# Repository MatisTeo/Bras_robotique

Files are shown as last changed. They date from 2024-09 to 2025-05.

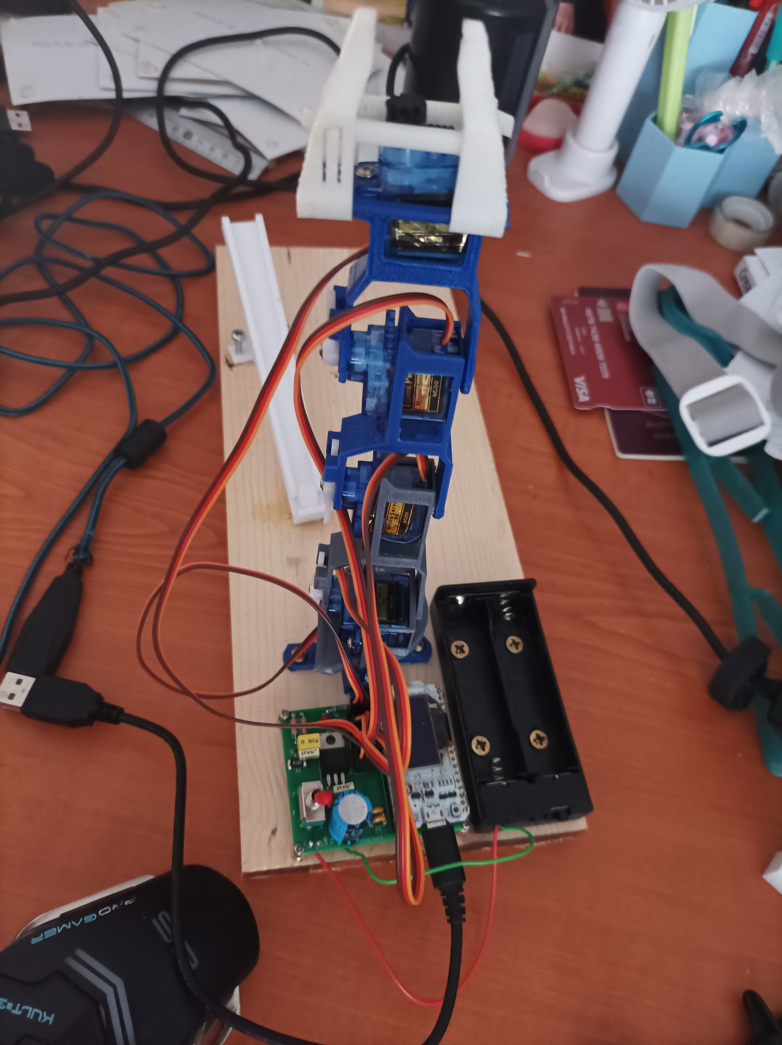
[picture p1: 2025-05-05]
Divers/photos/bras_robotique_assemblé_angle2.jpg

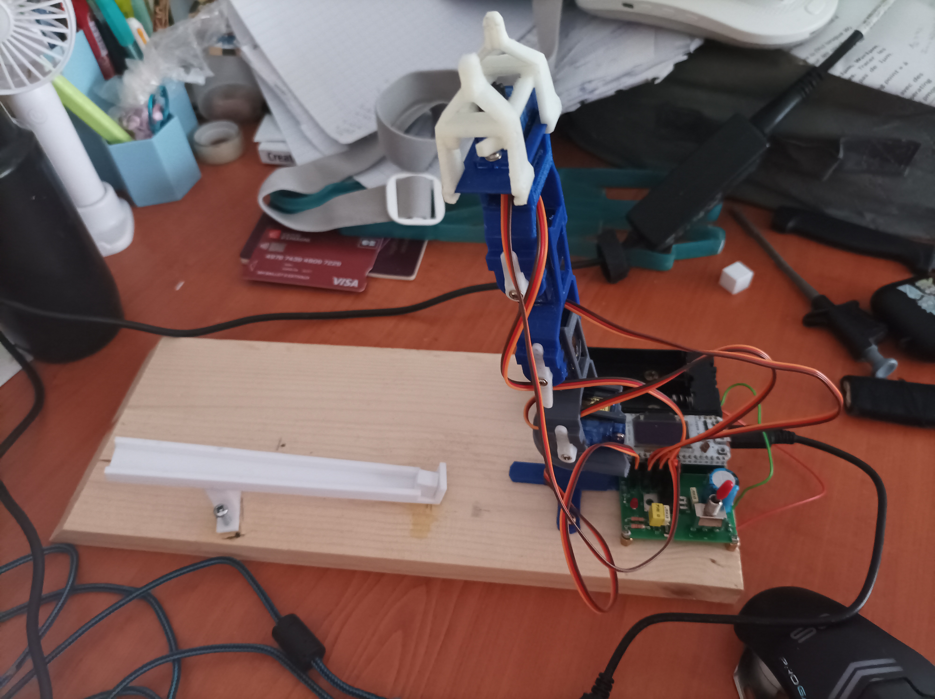
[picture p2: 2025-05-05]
Divers/photos/bras_robotique_assemblé_angle3.jpg

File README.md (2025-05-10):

# 🤖 Projet Bras Robotique Contrôlé par Gant Connecté

## 🎥 Démonstration vidéo
Regarder la vidéo sur YouTube (https://www.youtube.com/watch?v=8cOm21cPcBU)

## 📘 Présentation

Ce projet consiste à développer un **bras robotique à faible coût**, capable d'exécuter :
- des **mouvements automatiques prédéfinis**
- un **contrôle manuel à distance** à l'aide d’un **gant connecté**

L'objectif est de démontrer une alternative simple et économique pour la télémanipulation dans des environnements industriels.

## 🧠 Membres du projet
- **Téo Baillot d’Estivaux** — responsable software, modélisation 3D, banc de test
- **Matis Jaquet** — responsable hardware, PCB, assemblage électronique

## 🔧 Fonctionnalités
- Contrôle **automatique** via séquences programmées
- Contrôle **manuel en temps réel** via un gant avec capteur flex + MPU-6050
- Communication **sans fil via ESP-NOW (Wi-Fi)** entre gant et bras
- Structure imprimée en 3D, légère et modulaire
- Retour d’effort par détection de courant via INA219

## 📂 Contenu du dépôt
- `Hardware/` : Schémas et PCB sous KiCad
- `Software/` : Codes Arduino pour l’émetteur (gant) et le récepteur (bras)
- `Photos/Spécification/` : Images du montage
- `Memoire_Baillot_Jaquet.pdf` : Mémoire complet du projet (ELEC4 FISA 2024/2025)

## 🛠️ Composants utilisés
- 2x ESP32
- 1x MPU-6050 (accéléromètre)
- 1x capteur flex
- 5x servomoteurs SG90
- 1x INA219
- 1x bouton poussoir
- Câblage, breadboards, batteries

## 🚀 Instructions de montage
1. Imprimer les pièces 3D du bras
2. Souder les composants sur les PCB fournis
3. Assembler le gant en cousant les composants selon le schéma
4. Flasher les codes sur les ESP32 avec Arduino IDE
5. Alimenter les deux systèmes et tester les modes automatique et manuel

## 📎 Liens utiles
- [🔗 Dépôt GitHub](https://github.com/MatisTeo/Bras_robotique)
- [📄 Mémoire complet (PDF)](./Divers/Memoire_Baillot_Jaquet.pdf)

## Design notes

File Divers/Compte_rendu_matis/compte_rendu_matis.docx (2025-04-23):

Compte rendu des séances

Séance du 11 septembre :

Cette séance était destinée à choisir le projet. Nous avons donc décidé de faire une pince robotisée capable de récupérer le plus d'objets différents. Cette pince va être contrôlée grâce à un accéléromètre et un capteur de flexion. Le but est de faire bouger la main de droite à gauche pour faire bouger le bras articulé et de fermer le doigt pour fermer la pince grâce au capteur flex. Toutes les informations vont être transmises grâce à une connexion Bluetooth.

Séance du 23 septembre :

Durant cette séance, j'ai travaillé sur la création du git et la connexion du répertoire local de l'ordinateur au répertoire en ligne sur GitHub en utilisant une connexion SSH. De plus, pour développer le code nécessaire au fonctionnement des servomoteurs, j'ai dû installer l'environnement Arduino et les drivers pour piloter les ports de communication. Cette étape a pris plus de temps que prévu en raison de problèmes avec les drivers CH341 et CP210. Une fois ces problèmes résolus, tout était fonctionnel. Nous avons alors pu tester les servomoteurs pour comprendre leur fonctionnement.

Séance du 25 Novembre :

Au début de cette séance, les valeurs renvoyées par l'accéléromètre fluctuaient beaucoup trop pour pouvoir être traitées dans le code, ce qui provoquait des mouvements inopinés de la pince. Pour comprendre plus précisément la plage de tensions renvoyées par l'accéléromètre, j'ai décidé d'utiliser un oscilloscope pour observer la plage ainsi que les variations de tension.

Capture d'écran de l'oscilloscope en sortie de l'accéléromètre.

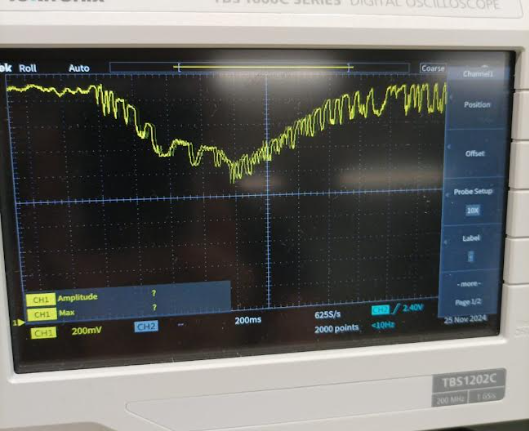
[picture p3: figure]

Interprétation :

Interprétation : Selon la capture d'écran de l'oscilloscope en sortie de l'accéléromètre, nous pouvons observer que les variations de tension de l'accéléromètre sont d'approximativement 600 millivolts pour un mouvement de 180° avec l'accéléromètre. Le problème que l'on peut constater, ce sont les perturbations - le bruit qui est de l'ordre de 250 à 200 millivolts. C'est donc ce bruit qui crée des perturbations lorsque l'on veut capturer la donnée de l'accéléromètre. Pour remédier à cela, nous avons eu l'idée de mettre un condensateur entre la sortie et le GND afin de lisser cette tension. Après d'autres mesures, malheureusement, cela n'a pas été utile et les perturbations restaient les mêmes. La deuxième solution a été la mise en place d'un filtre RC qui a pour valeur tau = 1/RC = 5ms, car nous capturons la valeur qui est renvoyée par l'accéléromètre tous les 50ms = 10 tau. Une fois le filtre en place, nous avons observé que les valeurs renvoyées étaient moins fluctuantes, les perturbations ont été divisées par 2, mais cela ne reste pas admissible. Une fois le filtre en place, nous avons observé que les valeurs renvoyées étaient moins fluctuantes, les perturbations ont été divisées par 2, mais cela ne reste pas admissible.

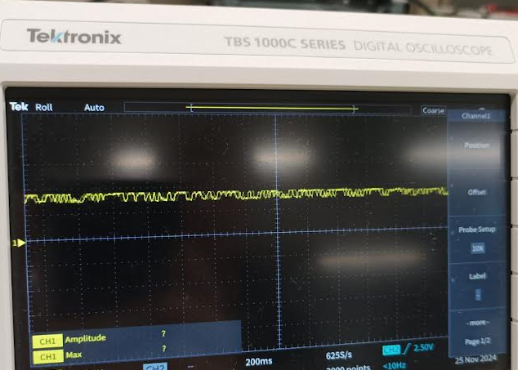
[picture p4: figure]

Séance du 26 Novembre :

J'ai débuté cette séance en consultant la documentation de l'accéléromètre pour essayer de comprendre l'origine de ces perturbations et notamment les variations de tension annoncées par le constructeur. Après cela, nous nous sommes aperçus que le problème venait plutôt du code, et après un réglage permettant de faire du filtrage numérique, il s'est avéré que les valeurs étaient enfin justes. Ensuite, je me suis penché sur la problématique de la connexion par Bluetooth et nous avons découvert que les cartes TTGO étaient déjà équipées de modules Bluetooth. Durant cette séance, j'en ai aussi profité pour commencer la conception du schéma électrique pour la carte qui sera mise sur le gant côté utilisateur.

Début du schéma préliminaire de la carte

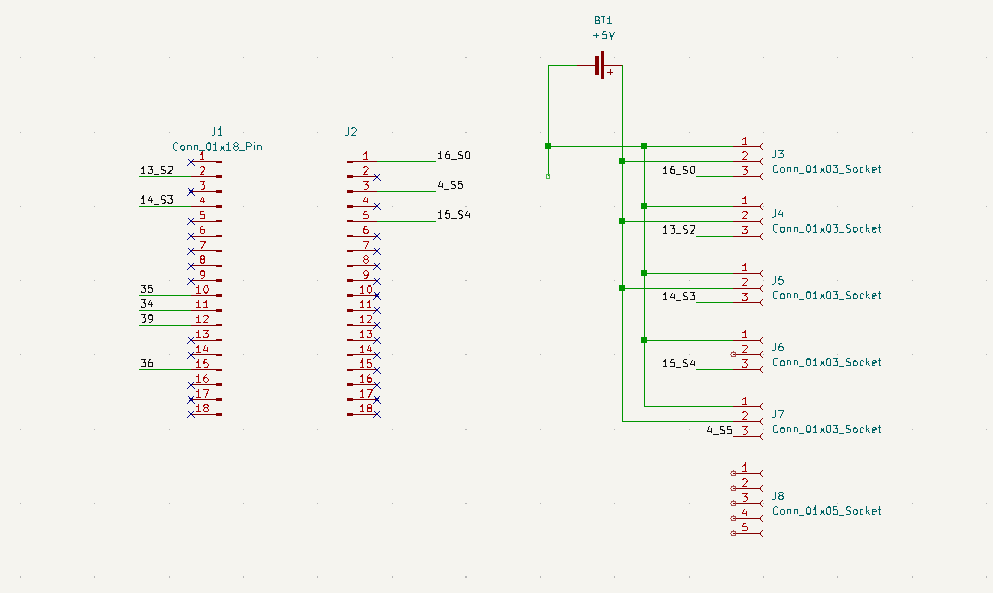
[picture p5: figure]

Sur ce schéma électrique, nous retrouvons simplement les connecteurs utilisés par la carte TTGO ainsi que les connecteurs des servomoteurs, afin de relier les deux ensembles.

Séance du 09 Decembre :

J'ai débuté la séance en reconfigurant le git. En fait j'ai réglé un problème qui durait depuis le début du projet et qui n'était pas compliqué. Le problème venait du fait que j'utilise GitLab dans mon entreprise, c'est-à-dire que à chaque fois que je revenais à l'entreprise git ne fonctionnait plus donc je refaisais une clé SSH, et à chaque fois que je revenais en projet git ne fonctionnait pas, la subtilité que je n'avais pas comprise c'est qu'il est possible d'avoir une clé sur un seul PC. Donc pour résoudre le problème j'ai ajouté la même clé dans les deux applications. Suite à cela j'ai pu réorganiser le git et enfin mettre mon compte rendu.

Ensuite j'ai commencé à faire le schéma de la carte qui se trouvera sur la main de l'utilisateur.

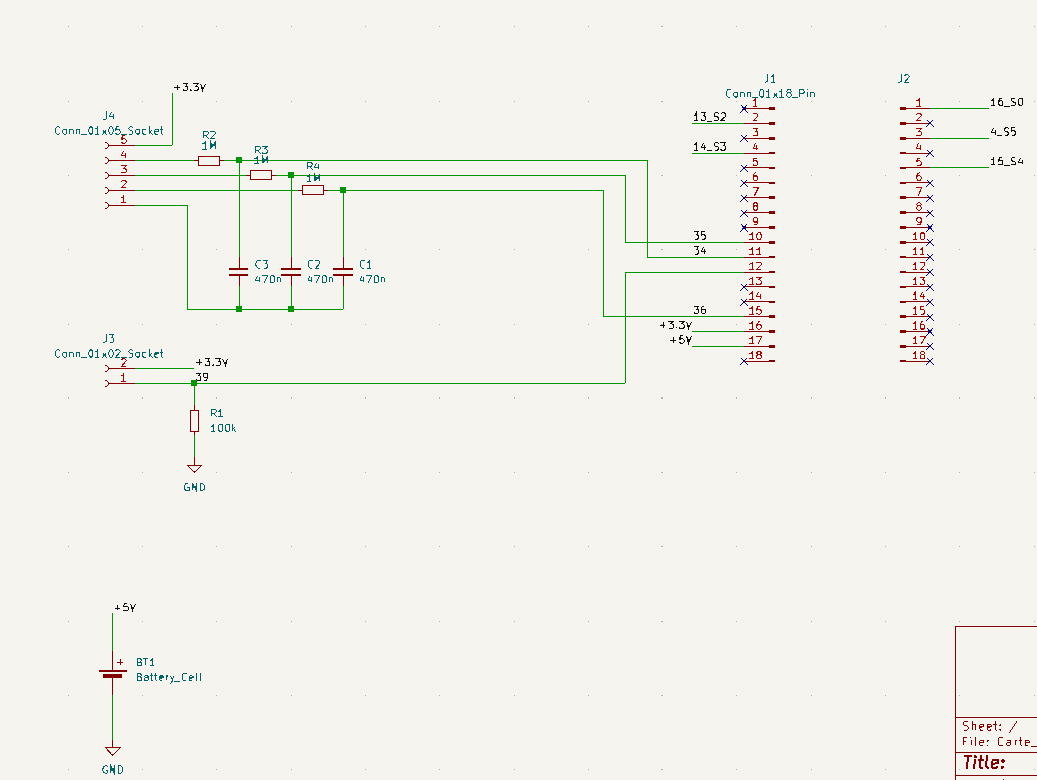
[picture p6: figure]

La question que je me suis posée était que si j'alimente la carte avec du +5V, est-ce que j'obtiendrai du +3.3V sur les pins du TTGO. Après avoir fait un setup de test sur la breadboard. Donc j'obtiens bien +3.3V sur un pin.

À la fin de la séance, nous avons enfin réussi à communiquer en wifi entre les deux TTGO et non en bluetooth comme c'était prévu initialement.

J'ai réfléchi sur les batteries à commander et nous avons besoin d'une alimentation de 3.7V disponible à Polytech.

Séance du 07/01/2025

Durant cette séance de travail, j'ai poursuivi le développement du schéma électrique en effectuant une revue détaillée pour garantir que toutes les fonctionnalités requises étaient bien intégrées. Une fois cette étape validée, je me suis concentré sur l'attribution des empreintes pour chaque composant. Pour assurer la faisabilité du projet, j'ai vérifié la disponibilité de tous les composants nécessaires dans les stocks de Polytech et commencé à les rassembler.

Parallèlement, j'ai initié le routage de la carte électronique destinée à être installée sur la main. En collaboration avec Téo, nous avons réalisé des tests de communication WIFI en utilisant des modules ESP32, ce qui nous a permis de valider le fonctionnement global du système.

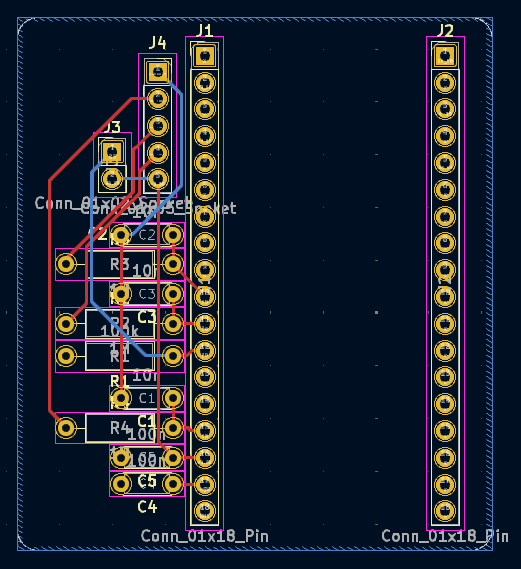
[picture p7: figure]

Seance du 03/02/2025

J’ai commencer la seance en faisant la deuxième carte se trouvant sur la voiture. (assignassion des empreinte et conception du schema)
En parallèle j’ai aidé teo pour le debug de la pince car après plusieurss semaine elle ne fonctionait plus correctement.
J’ai aussi determiné quelle broche du sp32 pour le bouton poussoir et aussi les batterie a utiliser, donc j’ai efectué le test pour savoir si le sp32 peut prendre 3.7 V au lieu de 3.3 V

Durant cette séance, mes activités se sont articulées autour de plusieurs tâches :

1. Conception de la seconde carte électronique pour le véhicule :
- Assignation des empreintes des composants
- Élaboration du PCB
2. Support technique sur la pince robotique :
- Assistance au debug avec Téo car cela faisait plusieurs semaines que l’on avait pas travaillé sur le projet et certaines fonctions devait être remise en route.
3. Étude d'alimentation et des entrées :
- Détermination des broches ESP32 compatibles pour le bouton poussoir
- Tests de compatibilité d'alimentation : validation du fonctionnement de l'ESP32 sous 3.7V (au lieu des 3.3V standard)
- Sélection des batteries adaptées au système

Ces travaux ont permis d'avancer sur la partie électronique du projet tout en résolvant des problèmes techniques existants.

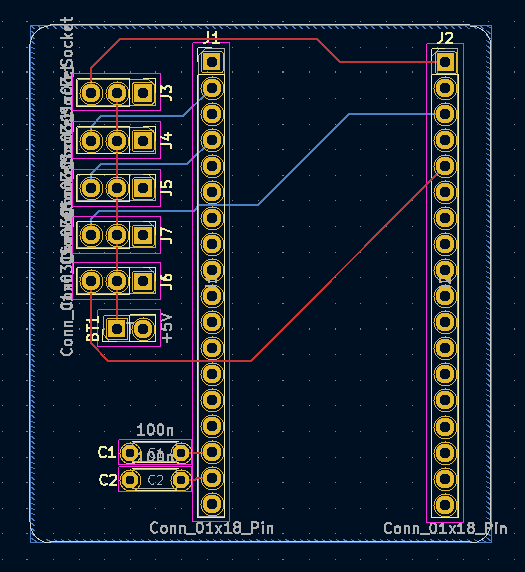
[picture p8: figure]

Séance du 25/02/2025

Durant cette séance, nous avons réceptionné les deux cartes (carte principale et carte pince). J'ai procédé au soudage des composants sur ces deux cartes, ce qui m'a permis d'identifier quelques points d'amélioration, notamment le besoin d'ajouter des annotations sur la carte.

À la fin de la séance, nous avons testé la pince équipée du nouvel accéléromètre et intégré la carte pince. Les résultats ont été concluants tant pour la carte que pour le fonctionnement de l'accéléromètre. Nous avons constaté une amélioration notable dans le contrôle de la pince.

Pour la prochaine séance (28/02/2025) :

- Identifier et intégrer les batteries appropriées aux cartes
- Tester l'ensemble pour valider le comportement
- Poursuivre la refonte totale des deux cartes

Séance 28/02/2025

Lors de cette séance, j'ai entrepris une refonte complète des deux cartes électroniques afin d'optimiser leur fonctionnement et leur intégration. Cette révision approfondie m'a permis d'améliorer l'agencement des composants et de résoudre les problèmes identifiés précédemment. Parallèlement, j'ai réceptionné les batteries adaptées à notre système. Nous avons aussi le support pour les batteries et nous devons réfléchir comment intégrer ce support a notre dispositif (la carte électronique). Il nous manque une batterie et un support de batteries sur les 3 nécessaires initialement.

Séance 10/03/25

Pendant cette séance, j’ai réfléchi à une nouvelle conception de carte pour la carte pince et la carte main en fonction des éléments d’amélioration remarqué grâce a l’utilisation des cartes reçu pour la première version. Il a aussi fallu modifier la carte main pour intégrer le nouvel accéléromètre numérique. Donc j’ai réuni les composants nécessaires à ajouter sur la carte.

Séance 11/02/25

J'ai poursuivi la conception des deux cartes électroniques.

En analysant les besoins en alimentation, j'ai réalisé qu'il fallait ajouter un régulateur de tension pour convertir le +8V des batteries en +5V nécessaire aux servomoteurs et à l'ESP32. J'ai donc revu le schéma électrique et le routage PCB en conséquence. J'ai également intégré des LED d'indication de mise sous tension pour un meilleur contrôle visuel du fonctionnement.

Durant la dernière heure, j'ai aidé Téo à résoudre des problèmes de connexion WiFi entre les deux modules ESP32.

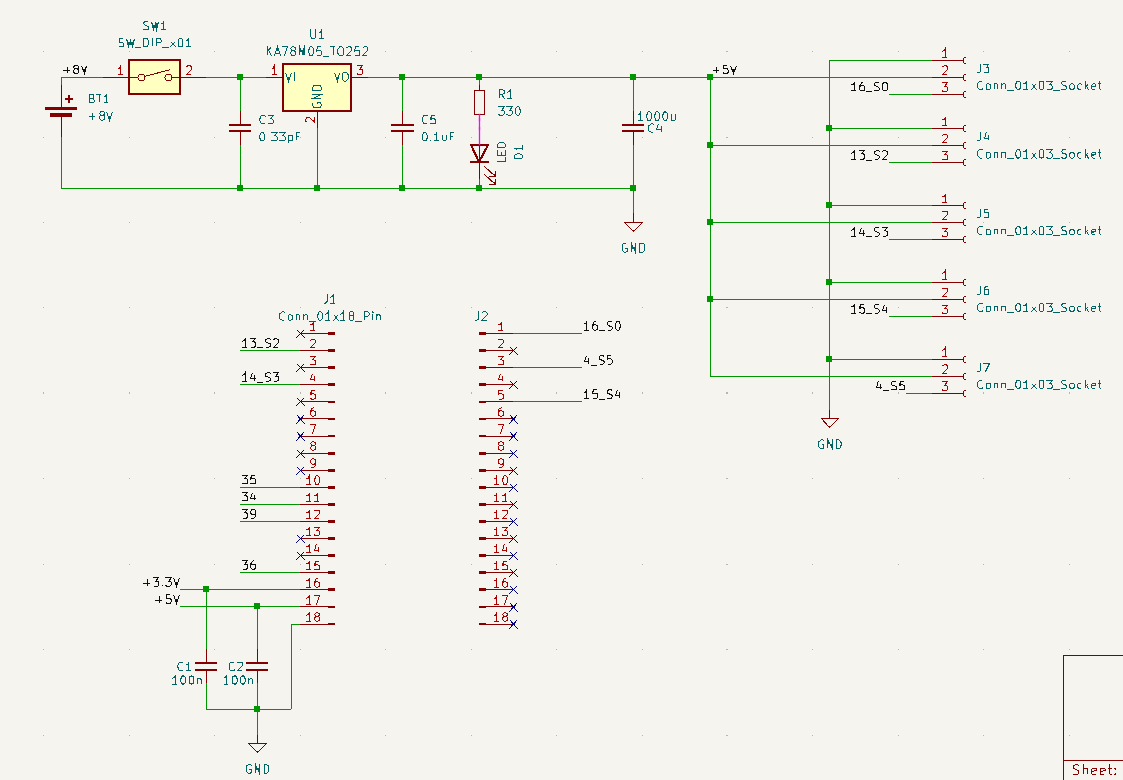
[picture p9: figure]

Schéma carte Pince.

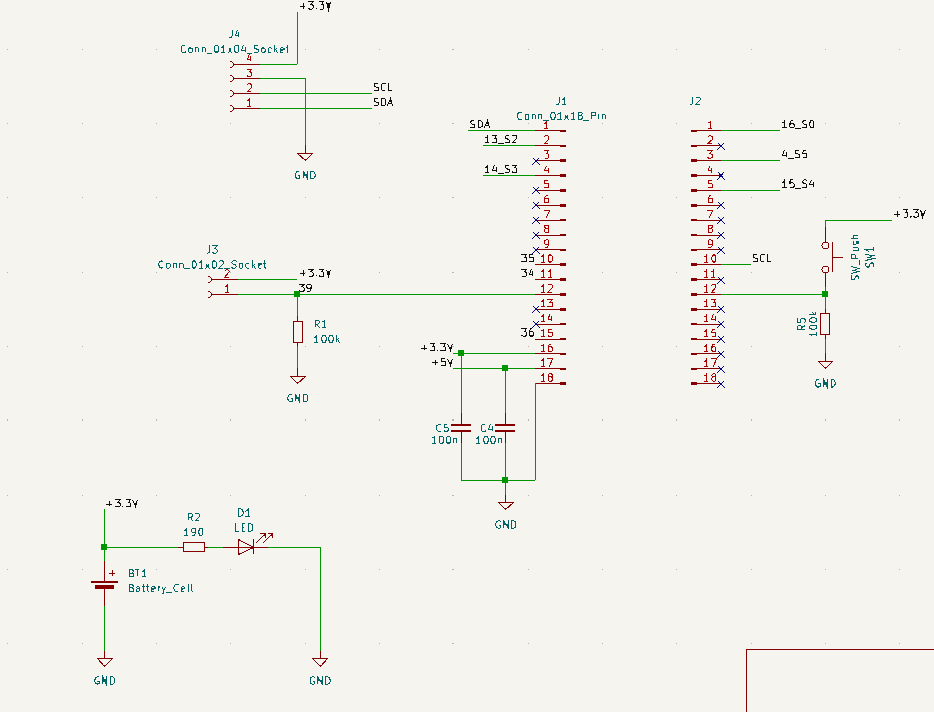
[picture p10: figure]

Schéma carte main

Séance du 25/03 :

  - Ajout de certains composants additionnels dans le schéma
  - Reprise du Lay-out.
  - Fixation de la pince sur la planche de bois.
  - Aide du debug avec Teo pour la communication Wifi entre les Deux ESP 32

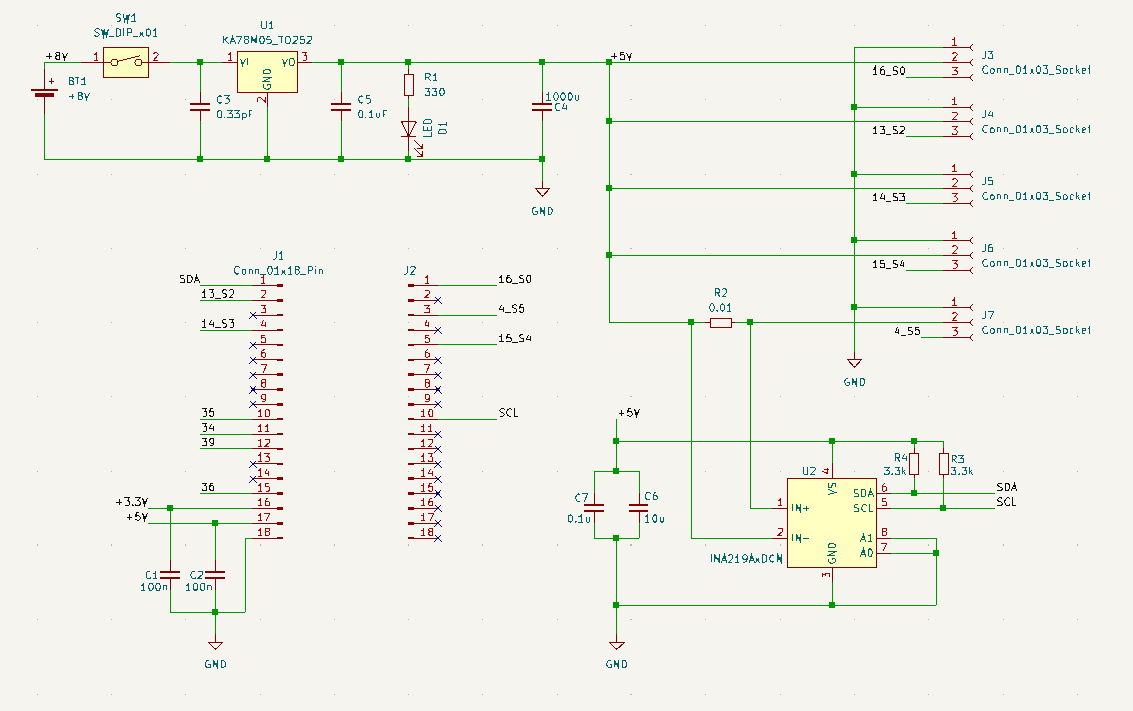
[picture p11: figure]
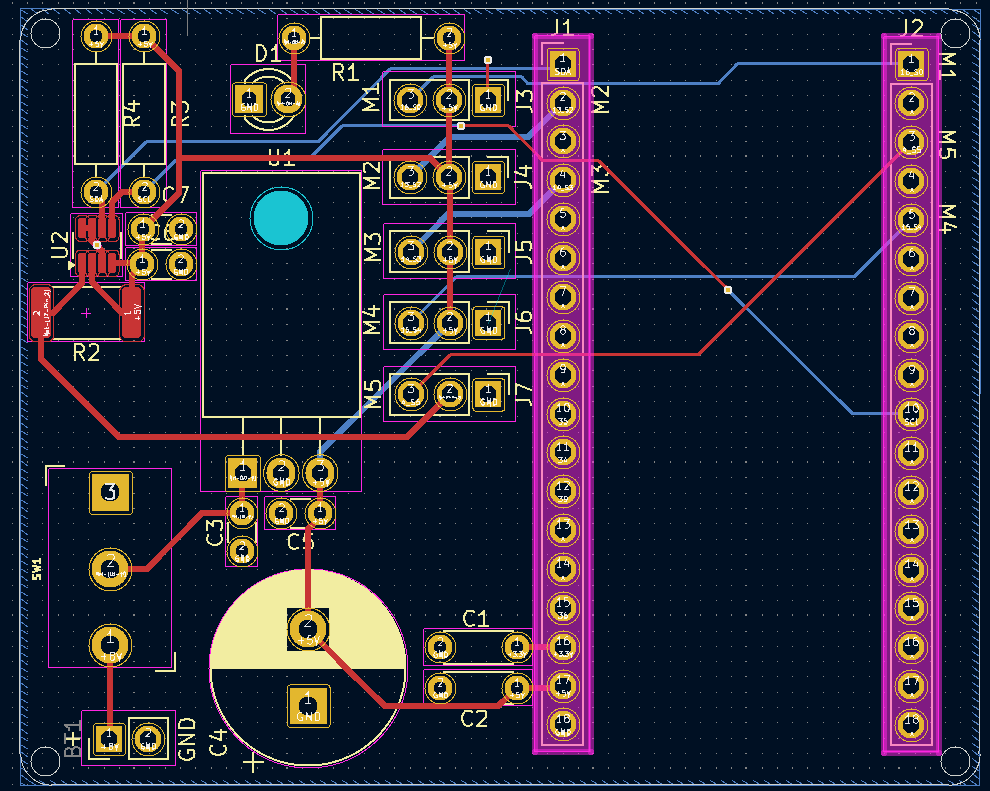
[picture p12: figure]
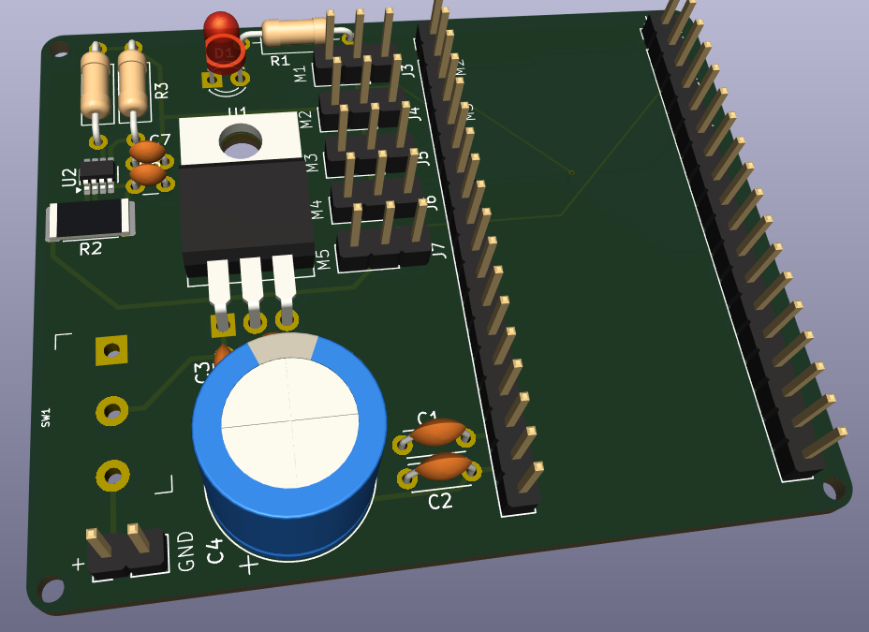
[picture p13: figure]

Réalisation lors des dernières Séances :

Après réception des cartes, j'ai procédé à la brasure de tous les composants. Ensuite, j'ai mis en marche les deux cartes en m'assurant qu'elles fonctionnaient correctement et qu'aucun court-circuit n'était présent.

Par la suite, Téo et moi avons tenté de résoudre le problème de la pince, particulièrement celui lié à l'engrenage dont les dents étaient trop petites. Finalement, nous avons identifié un dysfonctionnement dans l'une des deux pinces : le bouton-poussoir de la fonction automatique était connecté à une broche incorrecte de l'ESP32. Cette broche correspondait en réalité au RST du STM32.

Nous ne comprenons toujours pas pourquoi cette connexion a été réalisée ainsi, mais nous supposons qu'il s'agit d'un problème de communication, d'une incompréhension mutuelle.

2 Matis Jaquet

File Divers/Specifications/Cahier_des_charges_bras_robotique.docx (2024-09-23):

Matis Jaquet

Téo Baillot d’Estivaux

Cahier des charges du bras robotique

Contexte :

Dans un monde de plus en plus industriel, les robots et automates prennent de plus en plus de place.
Ainsi, le but du projet est de concevoir un bras robotique miniature à faible coût capable d’effectuer des tâches répétitives comme la manipulation d’objets.
Pour que le bras robotique puisse répondre à plus de besoins, il devra également être pilotable manuellement à l’aide d’un gant.
Enfin, pour augmenter la portée d’action de ce bras robotisé, on pourra le fixer sur une base roulante.

Définition des objectifs du projet:

Phase 1 :

Concevoir un bras robotique commandé par Bluetooth à l’aide d’un gant qui comportera différents capteurs afin de contrôler les mouvements du bras robotique. Un bouton sera également ajouté pour permettre au bras robotique d’effectuer des mouvements répétitifs afin de déplacer des objets comme dans les chaînes d’assemblage.

Phase 2 :

Lorsque la première phase sera terminée, nous fixerons notre bras robotique sur une base roulante pour augmenter son rayon d’action qui sera contrôlée par un autre gant ou un joystick, et qui permettra ainsi d’avoir un bras robotique mobile.

Spécifications fonctionnelles :

Le bras robotique devra :

- Être capable de bouger selon 4 axes.
- Avoir une pince permettant d’attraper de petits objets.
- Être capable de faire des mouvements répétitifs pour déplacer des objets d’un point A a un point B comme dans les chaînes d’assemblage.
- Pouvoir être contrôlé manuellement en temps réel à l’aide d’un gant.
- Être capable d’effectuer des mouvements précis et rapides.

La base roulante devra :

- Être capable de se dépasser d’un point A à un point B.
- Supporter le poids et les dimensions du bras robotique.
- Être contrôlable par un gant ou un joystick pour gérer ses déplacements en temps réel.
- Être suffisamment basse en termes de hauteur pour pouvoir permettre l’utilisation du bras robotique.

Contraintes techniques et temporelles :

- Durée de 2 semestres.
- Faire une pince relativement petite de sorte à pouvoir la faire tenir sur la base roulante.

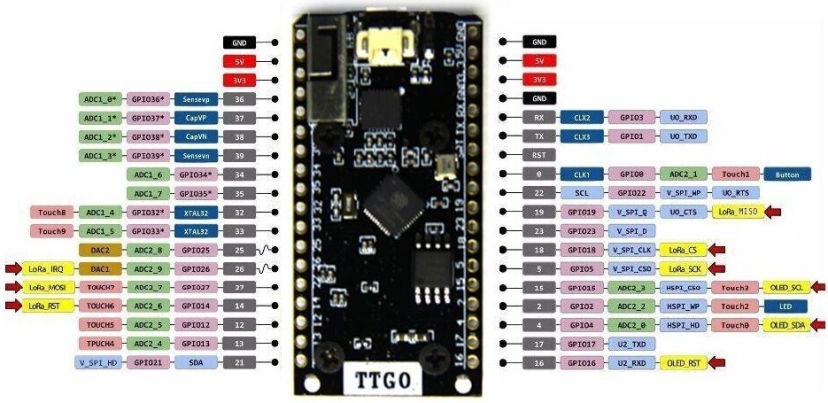
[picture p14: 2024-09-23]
Divers/photos/TTGO-LoRa-Board-Pinout.webp

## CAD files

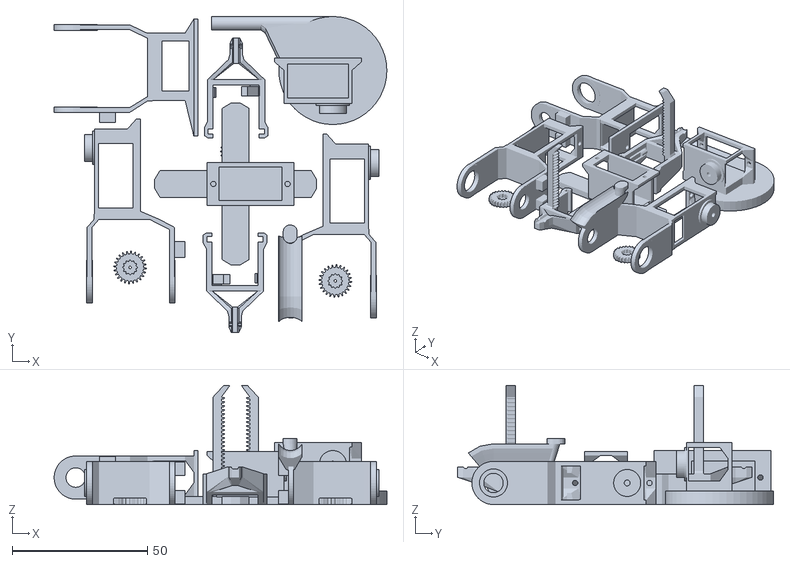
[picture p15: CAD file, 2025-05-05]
Modelisation 3D/Impressions_3d.stl
123.2 x 117.0 x 44.1

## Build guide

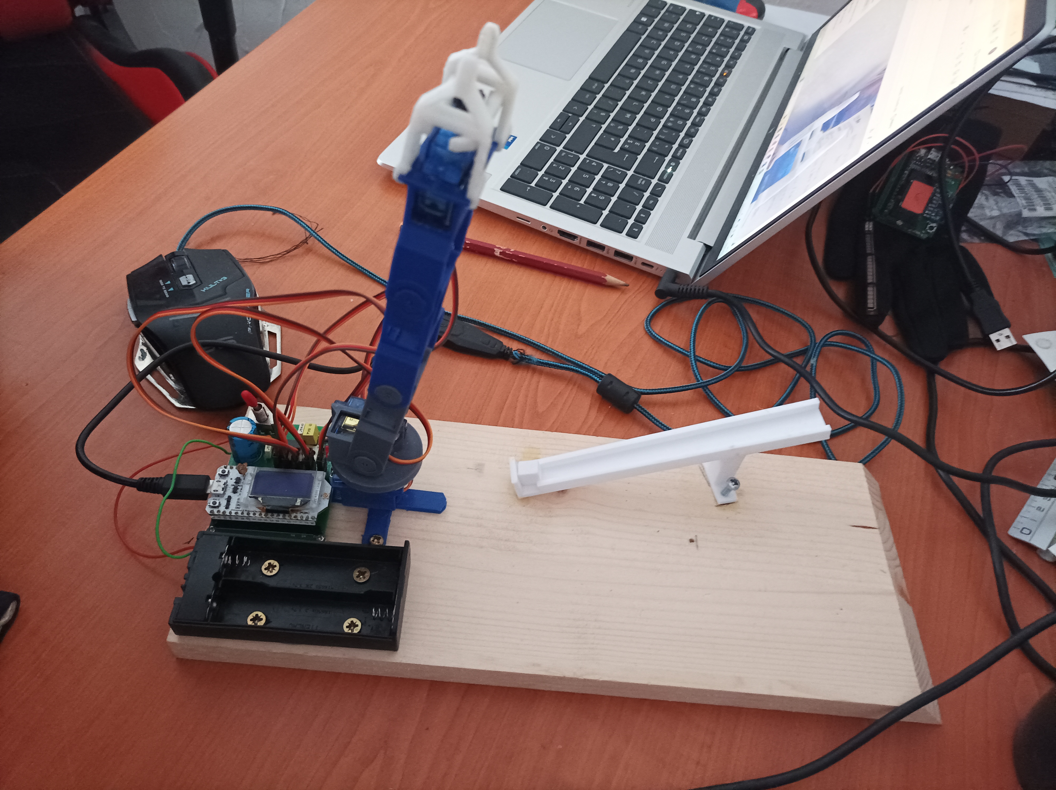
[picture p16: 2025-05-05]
Divers/photos/bras_robotique_assemblé_angle1.jpg

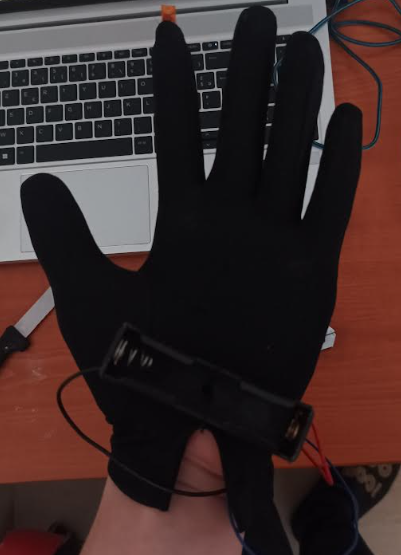
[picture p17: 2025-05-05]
Divers/photos/gant_assemblé_angle2.jpg.png

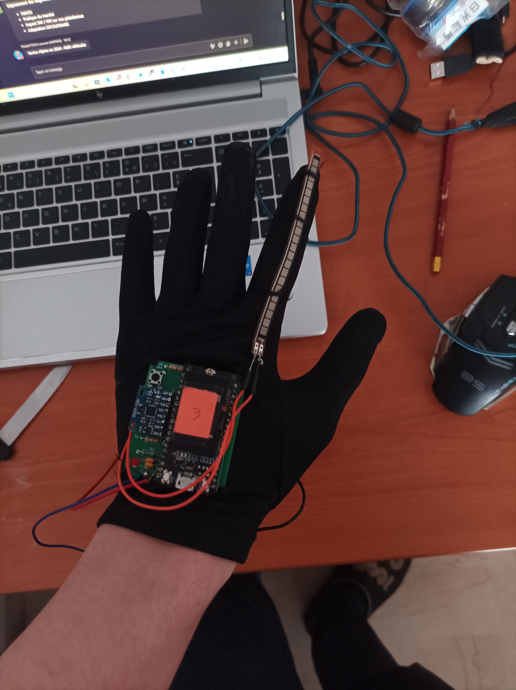
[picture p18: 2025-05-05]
Divers/photos/gant_assemblé_angle1.jpg

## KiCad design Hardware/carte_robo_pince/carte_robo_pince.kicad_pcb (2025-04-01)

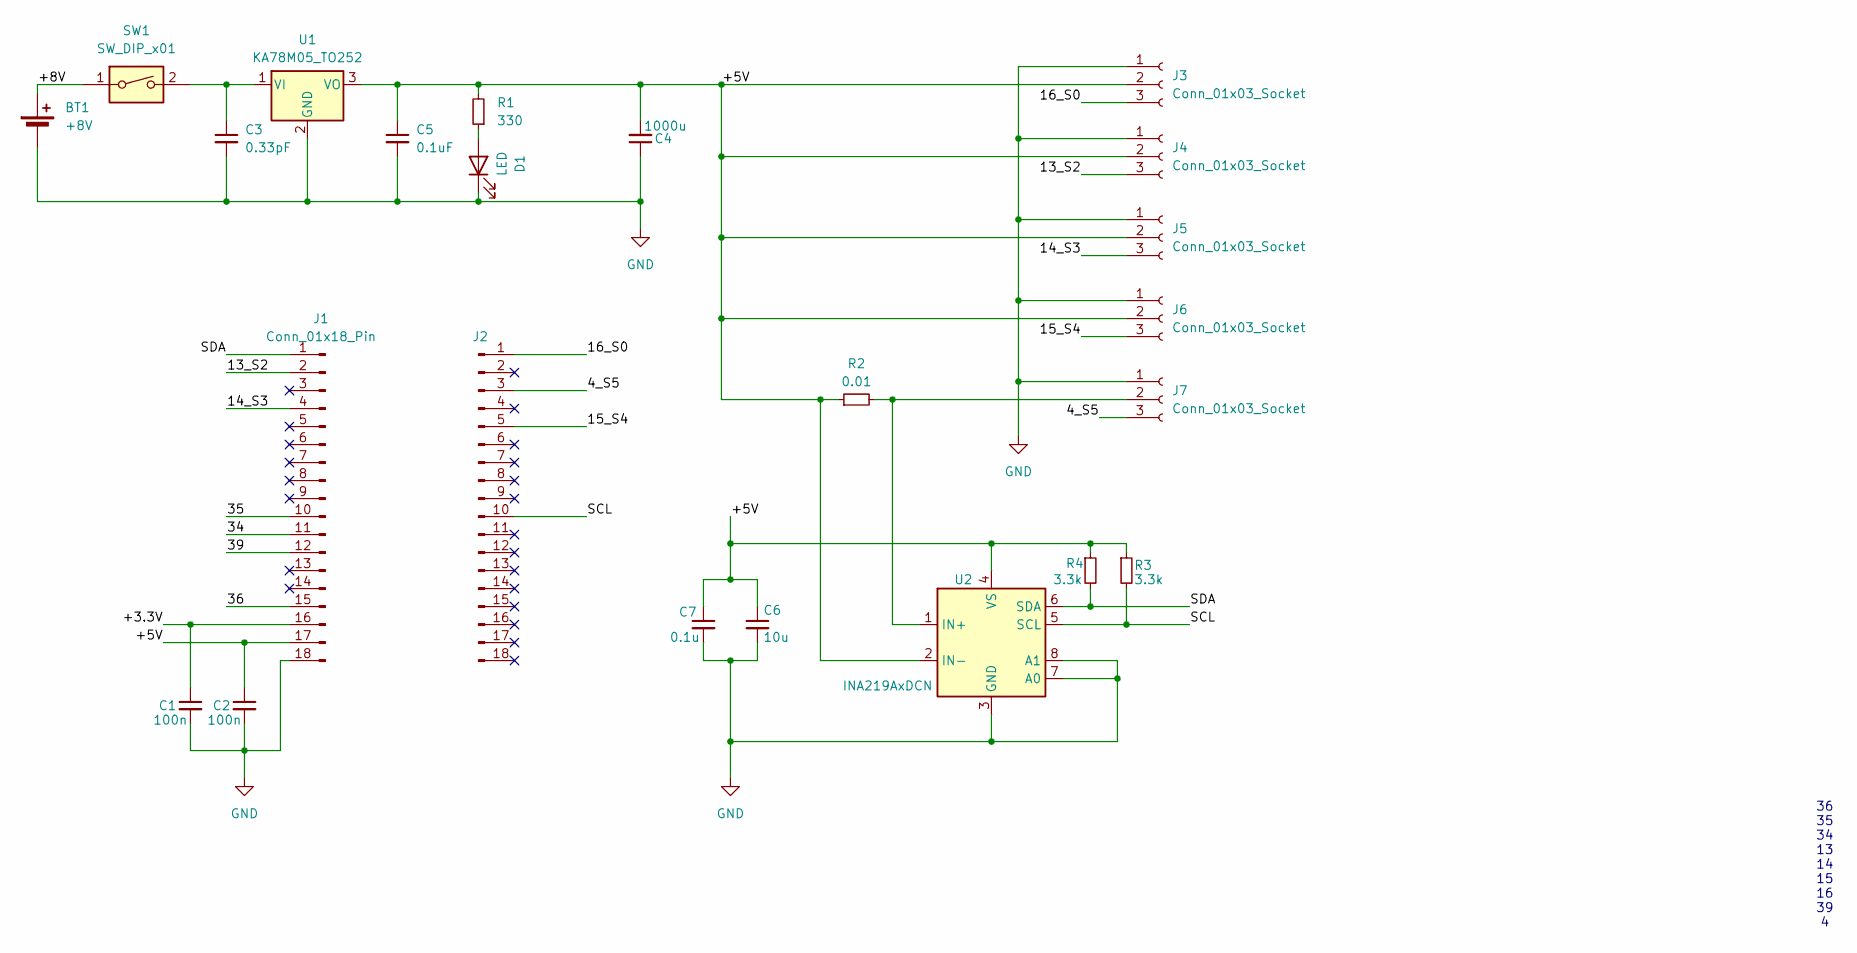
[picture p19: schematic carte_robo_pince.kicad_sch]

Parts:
BT1: +8V; PinHeader_1x02_P2.54mm_Vertical
C1, C2: 100n; C_Disc_D4.3mm_W1.9mm_P5.00mm
C3: 0.33pF; C_Disc_D3.0mm_W1.6mm_P2.50mm
C4: 1000u; CP_Radial_D12.5mm_P5.00mm
C5: 0.1uF; C_Disc_D3.0mm_W1.6mm_P2.50mm
C6: 10u; C_Disc_D3.0mm_W1.6mm_P2.50mm
C7: 0.1u; C_Disc_D3.0mm_W1.6mm_P2.50mm
D1: LED; LED_D3.0mm
J1, J2: Conn_01x18_Pin; PinHeader_1x18_P2.54mm_Vertical
J3, J4, J5, J6, J7: Conn_01x03_Socket; PinHeader_1x03_P2.54mm_Vertical
R1: 330; R_Axial_DIN0207_L6.3mm_D2.5mm_P10.16mm_Horizontal
R2: 0.01; R_2512_6332Metric
R3, R4: 3.3k; R_Axial_DIN0207_L6.3mm_D2.5mm_P10.16mm_Horizontal
SW1: SW_DIP_x01; SW_slide-03_P5_THT
U1: KA78M05_TO252; TO-220-3_Horizontal_TabDown
U2: INA219AxDCN; SOT-23-8

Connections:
/4_S5: J2.3, J7.3
/13_S2: J1.2, J4.3
/14_S3: J1.4, J5.3
/15_S4: J2.5, J6.3
/16_S0: J2.1, J3.3
/34: J1.11
/35: J1.10
/36: J1.15
/39: J1.12
/+3.3V: C1.1, J1.16
/+5V: C2.1, C4.2, C5.1, C6.1, C7.1, J1.17, J3.2, J4.2, J5.2, J6.2, R1.2, R2.1, R3.1, R4.1, U1.3 (VO), U2.2 (IN-), U2.4 (VS)
/+8V: BT1.1 (+), SW1.1
/SCL: J2.10, R3.2, U2.5 (SCL)
/SDA: J1.1, R4.2, U2.6 (SDA)
GND: BT1.2 (-), C1.2, C2.2, C3.2, C4.1, C5.2, C6.2, C7.2, D1.1 (K), J1.18, J3.1, J4.1, J5.1, J6.1, J7.1, U1.2 (GND), U2.3 (GND), U2.7 (A0), U2.8 (A1)
unnamed: D1.2 (A), R1.1
unnamed: J7.2, R2.2, U2.1 (IN+)
unnamed: C3.1, SW1.2, U1.1 (VI)

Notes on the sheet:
36 35 34 13 14 15 16 39 4

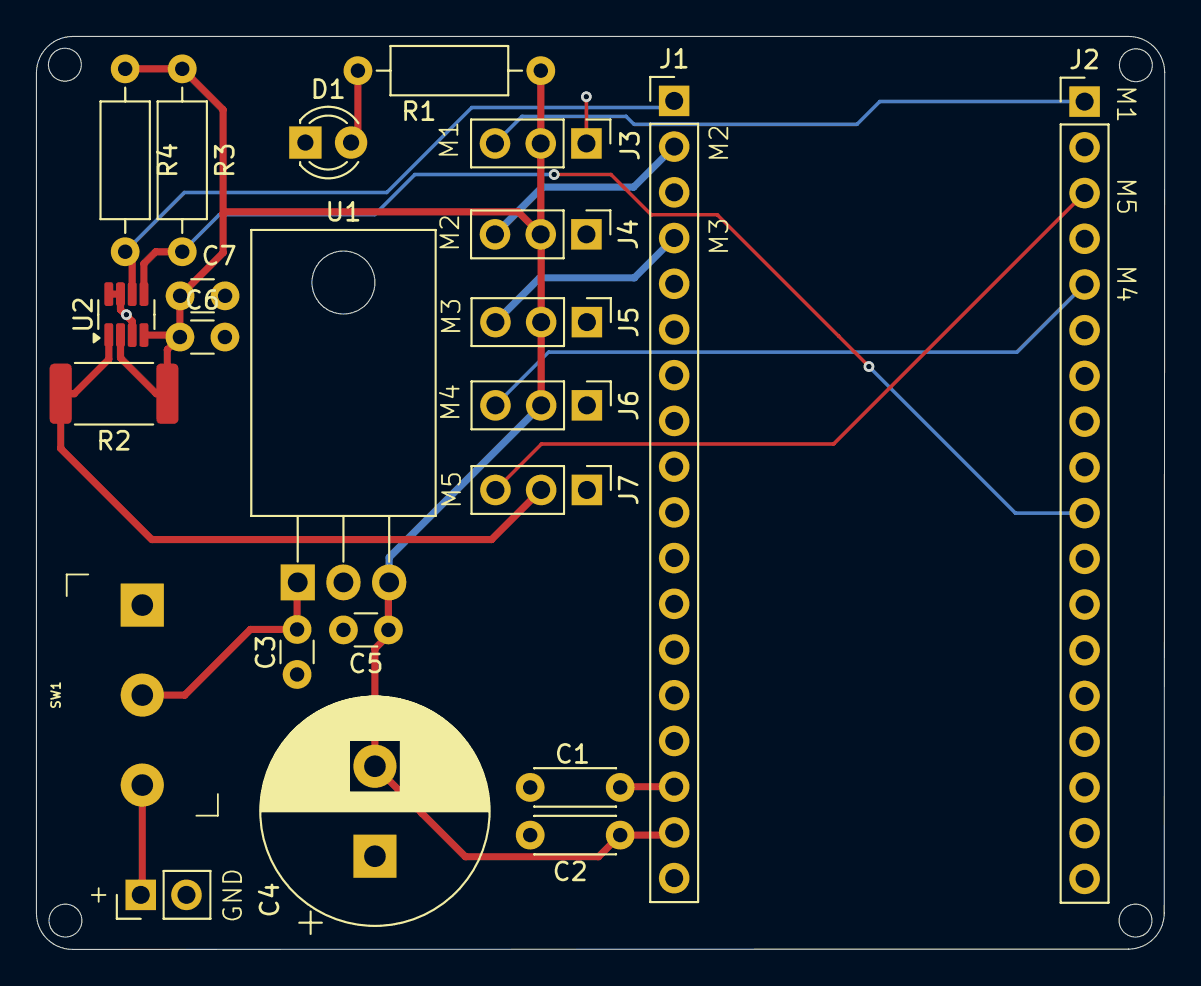
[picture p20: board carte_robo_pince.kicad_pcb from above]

Board: 2 copper layers, 62.7 x 50.7 mm, 23 parts (0 on the bottom side), 14 nets.

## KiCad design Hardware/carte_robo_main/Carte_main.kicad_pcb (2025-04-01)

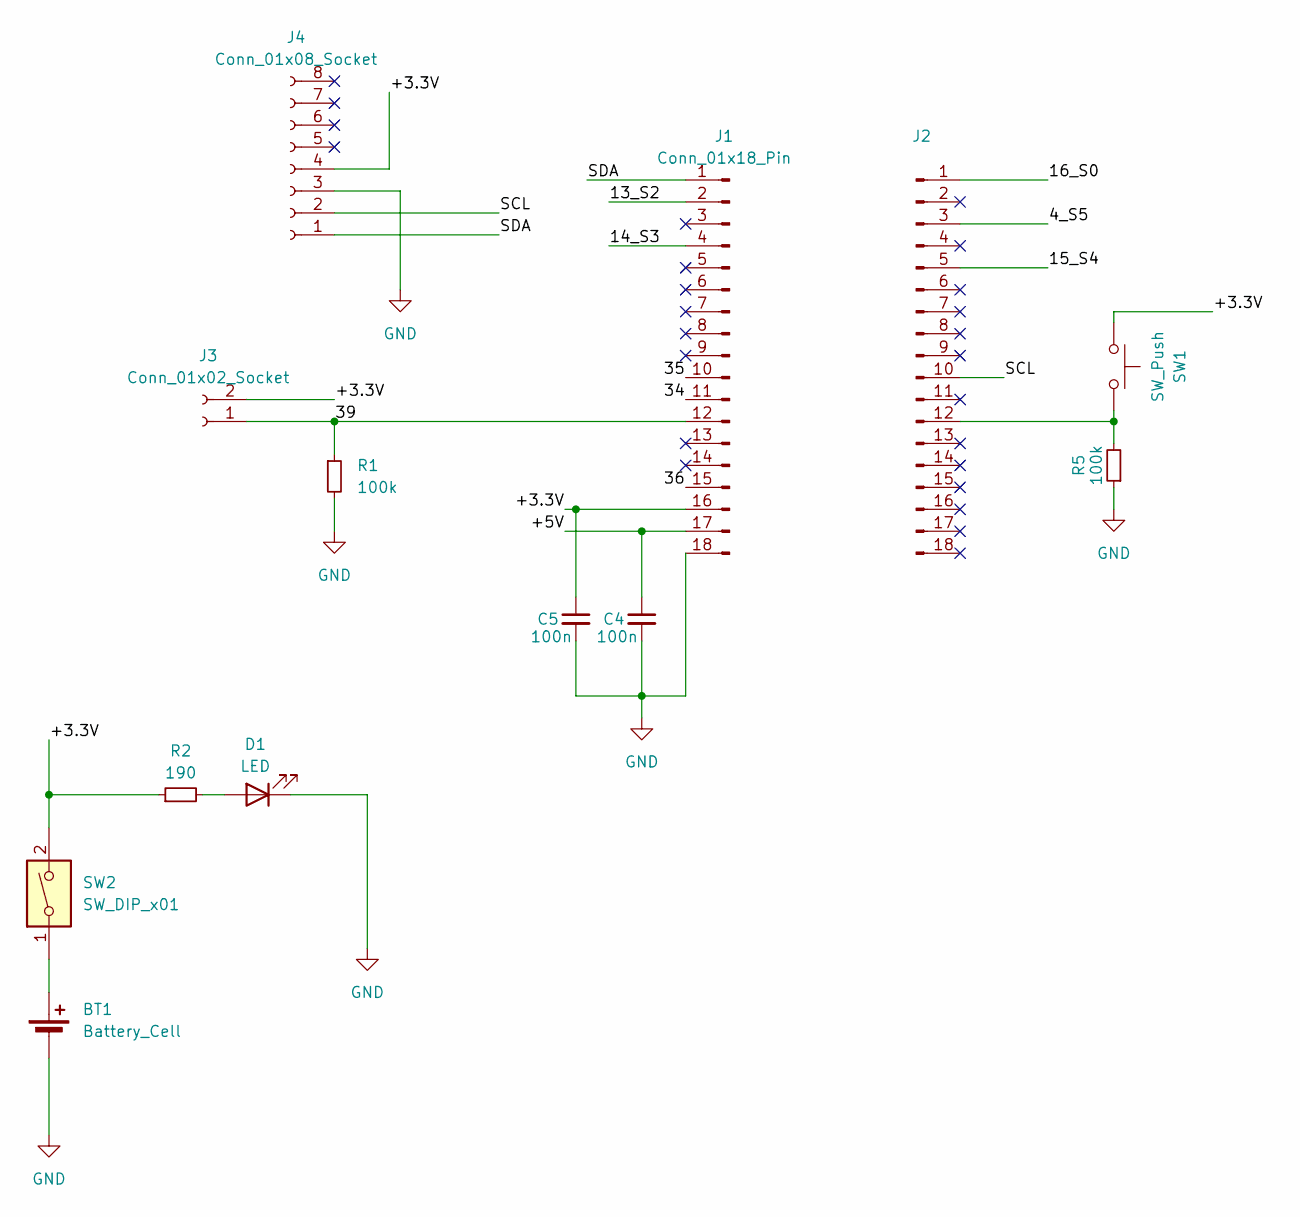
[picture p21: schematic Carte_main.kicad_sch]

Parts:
BT1: Battery_Cell; PinHeader_1x02_P2.54mm_Vertical
C4, C5: 100n; C_Disc_D4.3mm_W1.9mm_P5.00mm
D1: LED; LED_D3.0mm
J1, J2: Conn_01x18_Pin; PinHeader_1x18_P2.54mm_Vertical
J3: Conn_01x02_Socket; PinHeader_1x02_P2.54mm_Vertical
J4: Conn_01x08_Socket; PinHeader_1x08_P2.54mm_Vertical
R1, R5: 100k; R_Axial_DIN0207_L6.3mm_D2.5mm_P10.16mm_Horizontal
R2: 190; R_Axial_DIN0207_L6.3mm_D2.5mm_P10.16mm_Horizontal
SW1: SW_Push; SW_PUSH_6mm_H5mm
SW2: SW_DIP_x01; SW_slide-03_P5_THT

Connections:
/4_S5: J2.3
/13_S2: J1.2
/14_S3: J1.4
/15_S4: J2.5
/16_S0: J2.1
/34: J1.11
/35: J1.10
/36: J1.15
/39: J1.12, J3.1, R1.1
/+3.3V: C5.1, J1.16, J3.2, J4.4, R2.1, SW1.1, SW2.2
/+5V: C4.1, J1.17
/SCL: J2.10, J4.2
/SDA: J1.1, J4.1
GND: BT1.2 (-), C4.2, C5.2, D1.1 (K), J1.18, J4.3, R1.2, R5.1
unnamed: BT1.1 (+), SW2.1
unnamed: D1.2 (A), R2.2
unnamed: J2.12, R5.2, SW1.2

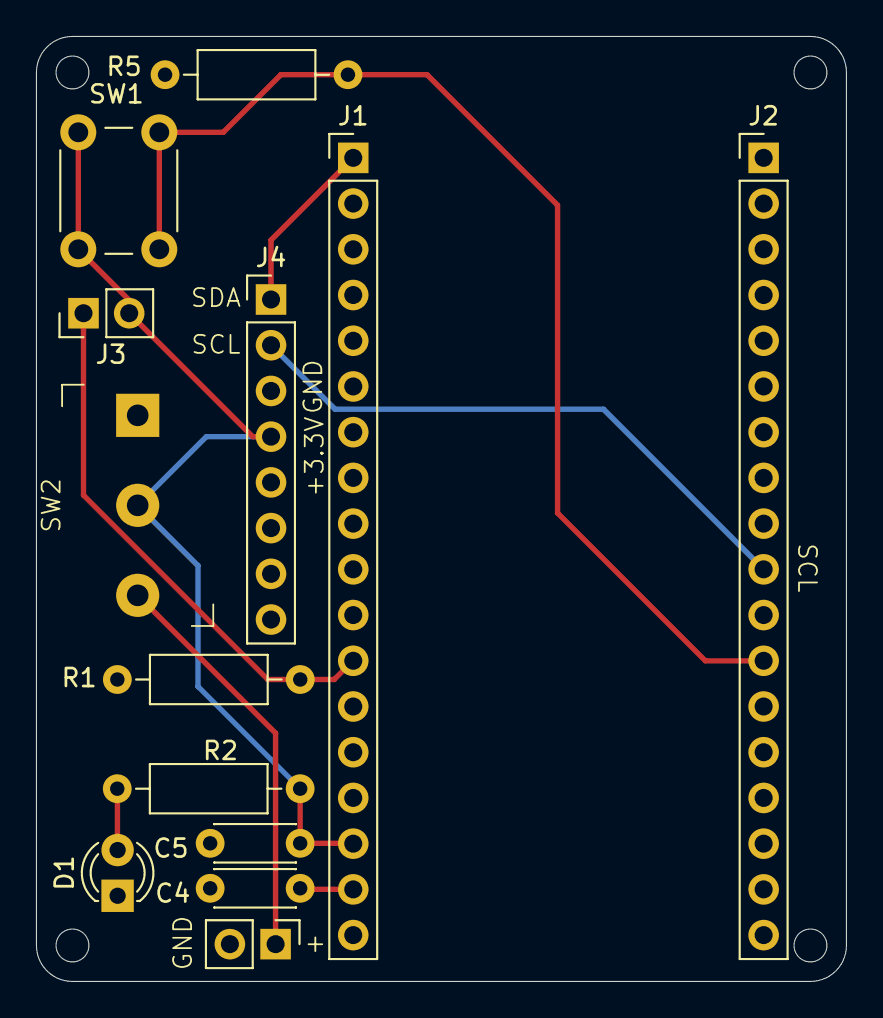
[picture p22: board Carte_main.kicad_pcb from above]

Board: 2 copper layers, 45.0 x 52.5 mm, 13 parts (0 on the bottom side), 9 nets.

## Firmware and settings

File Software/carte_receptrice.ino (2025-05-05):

#include <ESP32Servo.h>       
#include <esp_now.h>            
#include <WiFi.h>          
#include <Adafruit_INA219.h>     

#define PIN_SERVO 16            // Définition de la broche pour le servo SG90
#define PIN_SERVO2 13           // Définition de la broche pour le servo SG902
#define PIN_SERVO3 14           // Définition de la broche pour le servo SG903
#define PIN_SERVO4 15           // Définition de la broche pour le servo SG904
#define SERVO_PIN_5 4           // Définition de la broche pour le servo SG905

Adafruit_INA219 ina219;        //Création d'une instance de l'INA

Servo sg90;                    // Déclaration de l'objet servo pour SG90 (Servo contrôlé par l'axe X de l'accéléromètre)
Servo sg902;                   // Déclaration de l'objet servo pour SG902 (Servo du bas contrôlé par l'axe Y de l'accéléromètre)
Servo sg903;                   // Déclaration de l'objet servo pour SG903 (Servo du milieu contrôlé par l'axe Y de l'accéléromètre)
Servo sg904;                   // Déclaration de l'objet servo pour SG904 (Servo du haut contrôlé par l'axe Y de l'accéléromètre)
Servo sg905;                   // Déclaration de l'objet servo pour SG905 (Servo pour l'ouverture et la fermeture de la pince contrôlé par le capteur flex)

const int FLEX_MIN = 3100;      // Définition de la valeur minimale du capteur flex
const int FLEX_MAX = 2800;      // Définition de la valeur maximale du capteur flex
const int SERVO_MIN_ANGLE = 3;  // Définition de l'angle minimum pour les servos
const int SERVO_MAX_ANGLE = 60; // Définition de l'angle maximum pour les servos
const int SERVO_MIN_ANGLE_FLEX = 2; // Définition de l'angle maximum pour le servo du capteur flex
const int ANGLE_CHANGE_THRESHOLD = 8; // Seuil à dépasser pour changer l'angle du servo dans certains cas
const int CourantMax=-100; // courant maximum à ne pas dépasser pour ne pas faire forcer les servos moteurs

// Variables pour le mode automatique
unsigned long lastMoveTime = 0;
int sequenceStep = 0;
const int delayBetweenMovements = 10; // en millisecondes
const int pauseBetweenPositions = 0; // pause entre positions en millisecondes

float currentAngleSg90 = 0;    // Variable pour suivre l'angle actuel du servo SG90
float currentAngleSg902 = 0;   // Variable pour suivre l'angle actuel du servo SG902
float currentAngleSg903 = 0;   // Variable pour suivre l'angle actuel du servo SG903
float currentAngleSg904 = 0;   // Variable pour suivre l'angle actuel du servo SG904
float currentAngleSg905 = 0;   // Variable pour suivre l'angle actuel du servo SG905

// Variables pour la gestion du bouton
bool buttonPressed = false;    // Pour détecter si le bouton a été pressé
bool prevButtonState = false;  // État précédent du bouton
unsigned long lastDebounceTime = 0;
const unsigned long debounceDelay = 50;  // Délai anti-rebond en ms

struct SensorData {            // Définition d'une structure pour contenir les données du capteur
    float accelX;              // Accéléromètre sur l'axe X
    float accelY;              // Accéléromètre sur l'axe Y
    int flex;                  // Valeur du capteur flex
    bool buttonState;          // État du bouton: true = appuyé, false = relâché
};

SensorData receivedData;       // Déclaration de l'objet `receivedData` pour stocker les données reçues
bool currentMode = true;       // Mode par défaut: manuel (true = manuel, false = automatique)

void adjustServoAngleIfNeeded(Servo &servo, float &currentAngle, int targetAngle) {
  float current_mA = ina219.getCurrent_mA();
    if(currentAngle < targetAngle) {
      servo.write(targetAngle);
      currentAngle = targetAngle;
    }
    else if (currentAngle > targetAngle) {
        // Fermeture lente : angle diminue doucement
        for (int pos = currentAngle; pos >= targetAngle; pos-=0.25) {
            current_mA = ina219.getCurrent_mA();

            if (current_mA < CourantMax) {
                Serial.println("La pince force");
                break;
            }

            servo.write(pos);
            delay(75);  // ralentir la fermeture
            currentAngle = pos;
        }
    }
}


// Fonction pour déplacer un servo progressivement
void moveServoSmooth(Servo &servo, int startPos, float endPos) {
    if (startPos < endPos) {
        for (int pos = startPos; pos <= endPos; pos++) {
            servo.write(pos);
            delay(delayBetweenMovements);
        }
    } else {
        for (int pos = startPos; pos >= endPos; pos--) {
            servo.write(pos);
            delay(delayBetweenMovements);
        }
    }
}

void moveServoSmoothManual(
    Servo &servo0, float &current0, int target0,  //  sg90
    Servo &servo1, float &current1, int target1,  // sg902
    Servo &servo2, float &current2, int target2,  //  sg903
    Servo &servo3, float &current3, int target3   // sg904
) {
    int maxSteps = max(max(abs(current0 - target0), abs(current1 - target1)),
                       max(abs(current2 - target2), abs(current3 - target3)));
    if (maxSteps == 0) return;

    float step0 = (target0 - current0) / maxSteps;
    float step1 = (target1 - current1) / maxSteps;
    float step2 = (target2 - current2) / maxSteps;
    float step3 = (target3 - current3) / maxSteps;

    float pos0 = current0;
    float pos1 = current1;
    float pos2 = current2;
    float pos3 = current3;

    for (int i = 0; i <= maxSteps; i++) {
      if(current0-pos0<ANGLE_CHANGE_THRESHOLD){
        servo0.write(round(pos0));
      }
      servo1.write(round(pos1));
      servo2.write(round(pos2));
      servo3.write(round(pos3));
      

      pos0 += step0;
      pos1 += step1;
      pos2 += step2;
      pos3 += step3;

      delay(10);
    }

    current0 = target0;
    current1 = target1;
    current2 = target2;
    current3 = target3;
}


// Fonction pour déplacer tous les servomoteurs avec un servo spécifique en premier
void moveToPosition(float pos1, int pos2, int pos3, int pos4, int pos5, int firstServo) {
    // Définition des constantes pour identifier les servos
    const int BASE = 1;    // sg90
    const int PREMIER = 2;  // sg902
    const int DEUXIEME = 3;   // sg903
    const int TROISIEME = 4; // sg904
    const int PINCE = 5;   // sg905
    
    // Sauvegarde des positions actuelles
    int currentPos1 = sg90.read();
    int currentPos2 = sg902.read();
    int currentPos3 = sg903.read();
    int currentPos4 = sg904.read();
    int currentPos5 = sg905.read();
    
    // Déplacer d'abord le servo spécifié
    switch(firstServo) {
        case BASE:
            moveServoSmooth(sg90, currentPos1, pos1);
            break;
        case PREMIER:
            moveServoSmooth(sg902, currentPos2, pos2);
            break;
        case DEUXIEME:
            moveServoSmooth(sg903, currentPos3, pos3);
            break;
        case TROISIEME:
            moveServoSmooth(sg904, currentPos4, pos4);
            break;
        case PINCE:
            moveServoSmooth(sg905, currentPos5, pos5);
            break;
    }
    
    // Déplacer ensuite les autres servos
    if (firstServo != BASE) moveServoSmooth(sg90, currentPos1, pos1);
    if (firstServo != DEUXIEME) moveServoSmooth(sg903, currentPos3, pos3);
    if (firstServo != TROISIEME) moveServoSmooth(sg904, currentPos4, pos4);
    if (firstServo != PINCE) moveServoSmooth(sg905, currentPos5, pos5);
    if (firstServo != PREMIER) moveServoSmooth(sg902, currentPos2, pos2);
    
    // Pause pour permettre l'exécution de l'action
    delay(pauseBetweenPositions);
}

// Version simplifiée qui utilise BASE comme servo par défaut à bouger en premier
void moveToPosition(float pos1, int pos2, int pos3, int pos4, int pos5) {
    const int BASE = 1;
    moveToPosition(pos1, pos2, pos3, pos4, pos5, BASE);
}

// Fonction à appeler lorsqu'on reçoit des données
void OnDataRecv(const esp_now_recv_info_t *recv_info, const uint8_t *incomingData, int len) {
    if (len == sizeof(receivedData)) {
        memcpy(&receivedData, incomingData, sizeof(receivedData)); // Copie les données reçues
        
        // Gestion du bouton avec anti-rebond
        if (receivedData.buttonState != prevButtonState) {
            lastDebounceTime = millis();
        }
        
        // Si l'état du bouton est stable pendant assez longtemps
        if ((millis() - lastDebounceTime) > debounceDelay) {
            // Si le bouton est appuyé et n'était pas appuyé auparavant
            if (receivedData.buttonState && !buttonPressed) {
                buttonPressed = true;
                
                // Changer de mode
                currentMode = !currentMode;
                Serial.print("Mode changé: ");
                Serial.println(currentMode ? "Manuel" : "Automatique");
                
                // Réinitialiser la séquence automatique si on entre en mode automatique
                if (!currentMode) {
                    sequenceStep = 0;
                    lastMoveTime = millis();
                }
            } 
            // Si le bouton est relâché
            else if (!receivedData.buttonState) {
                buttonPressed = false;
            }
        }
        
        prevButtonState = receivedData.buttonState;
        
        // Si on est en mode manuel, traiter les données des capteurs
        if (currentMode) {
            modeManuel();
        }
        // Le mode automatique est géré dans la boucle principale
    }
}

// Fonction pour le mode manuel (contrôlé par les capteurs)
void modeManuel() {
    int servoAngle = map(receivedData.flex, FLEX_MIN, FLEX_MAX, SERVO_MAX_ANGLE, SERVO_MIN_ANGLE_FLEX);
    servoAngle = constrain(servoAngle, SERVO_MIN_ANGLE_FLEX, SERVO_MAX_ANGLE);
    adjustServoAngleIfNeeded(sg905, currentAngleSg905, servoAngle);
    currentAngleSg905 = servoAngle;

    int mappedAngleSg90 = map(receivedData.accelX, 12000, -12000, 0, 90);
    mappedAngleSg90 = constrain(mappedAngleSg90, SERVO_MIN_ANGLE, SERVO_MAX_ANGLE);
    currentAngleSg90 = mappedAngleSg90;

    int angle1, angle2, angle3;

    if (receivedData.accelY < -10000) {
        angle1 = 0; angle2 = 0; angle3 = 0;
    } else if (receivedData.accelY < -5400) {
        angle1 = map(receivedData.accelY, -10000, -5400, 0, 50);
        angle2 = 0;
        angle3 = map(receivedData.accelY, -10000, -5400, 0, 35);
    } else if (receivedData.accelY < -4250) {
        angle1 = map(receivedData.accelY, -5400, -4250, 50, 35);
        angle2 = map(receivedData.accelY, -5400, -4250, 0, 15);
        angle3 = map(receivedData.accelY, -5400, -4250, 35, 45);
    } else if (receivedData.accelY < -2000) {
        angle1 = map(receivedData.accelY, -4250, -2000, 35, 30);
        angle2 = map(receivedData.accelY, -4250, -2000, 15, 20);
        angle3 = 45;
    } else if (receivedData.accelY < 2000) {
        angle1 = map(receivedData.accelY, -2000, 2000, 30, 25);
        angle2 = map(receivedData.accelY, -2000, 2000, 20, 35);
        angle3 = 45;
    } else if (receivedData.accelY < 4000) {
        angle1 = map(receivedData.accelY, -800, 4000, 25, 20);
        angle2 = map(receivedData.accelY, -800, 4000, 35, 40);
        angle3 = 45;
    } else if (receivedData.accelY < 6000) {
        angle1 = map(receivedData.accelY, 1500, 6000, 20, 15);
        angle2 = map(receivedData.accelY, 1500, 6000, 40, 50);
        angle3 = 45;
    } else if (receivedData.accelY < 8000) {
        angle1 = map(receivedData.accelY, 3800, 8000, 15, 10);
        angle2 = map(receivedData.accelY, 3800, 8000, 50, 60);
        angle3 = 45;
    } else if (receivedData.accelY < 9000) {
        angle1 = map(receivedData.accelY, 6100, 9000, 10, 5);
        angle2 = map(receivedData.accelY, 6100, 9000, 60, 65);
        angle3 = 45;
    } else if (receivedData.accelY < 11000) {
        angle1 = map(receivedData.accelY, 8400, 11000, 5, 0);
        angle2 = map(receivedData.accelY, 8400, 11000, 65, 70);
        angle3 = 45;
    } else if (receivedData.accelY < 13000) {
        angle1 = 0;
        angle2 = map(receivedData.accelY, 10700, 13000, 70, 80);
        angle3 = map(receivedData.accelY, 10700, 13000, 45, 50);
    } else {
        angle1 = 0;
        angle2 = 75;
        angle3 = 65;
    }

    moveServoSmoothManual(
         sg90,   currentAngleSg90,   mappedAngleSg90,
         sg902,  currentAngleSg902,  angle1,
         sg903,  currentAngleSg903,  angle2,
         sg904,  currentAngleSg904,  angle3
    );


    currentAngleSg902 = angle1;
    currentAngleSg903 = angle2;
    currentAngleSg904 = angle3;
}


// Fonction pour exécuter la séquence automatique
void modeAutomatique() {
    const int PREMIER = 2;  // Valeur pour premier servo dans moveToPosition
    
    switch (sequenceStep) {
        case 0: // Position initiale
            moveToPosition(45, 0, 0, 0, 60, PREMIER);
            sequenceStep++;
            break;
            
        case 1: // Position 1
            Serial.println("Déplacement vers Position 1");
            moveToPosition(60, 14, 43, 67, 60);
            sequenceStep++;
            break;
            
        case 2: // Fermeture de la pince
            delay(750);
            Serial.println("Fermeture de la pince");
            moveServoSmooth(sg905, 60, 4);
            delay(pauseBetweenPositions);
            sequenceStep++;
            break;
            
        case 3: // Position 2
            delay(100);
            Serial.println("Déplacement vers Position 2");
            moveToPosition(61, 5, 42, 66, 4, PREMIER);
            sequenceStep++;
            break;
            
        case 4: // Position 3
            Serial.println("Déplacement vers Position 3");
            moveToPosition(58, 10, 30, 40, 4, PREMIER);
            sequenceStep++;
            break;
            
        case 5: // Position 4
            Serial.println("Déplacement vers Position 4");
            moveToPosition(60, 39, 11, 18, 4);
            sequenceStep++;
            break;
            
        case 6: // Ouverture de la pince
            delay(500);
            Serial.println("Ouverture de la pince");
            moveServoSmooth(sg905, 4, 60);
            delay(pauseBetweenPositions);
            sequenceStep++;
            break;
            
        case 7: // Pause avant de recommencer
            Serial.println("Redémarrage de la séquence");
            sequenceStep = 0; // Revenir au début de la séquence
            break;
    }
}

void setup() {
    Serial.begin(115200);        

    // Initialisation du capteur INA219
    if (!ina219.begin()) {
        Serial.println("Erreur d'initialisation du capteur INA219");
        while (1); // Arrêt du programme si le capteur n'est pas trouvé
    }

    WiFi.mode(WIFI_STA); // Configure l'ESP32 en mode WiFi

    // Initialisation d'ESP-NOW
    if (esp_now_init() != ESP_OK) {
        Serial.println("Erreur d'initialisation ESP-NOW");
        return;
    }

    esp_now_register_recv_cb(OnDataRecv); // Enregistre la fonction qui sera appelée à chaque réception de données

    sg90.attach(PIN_SERVO);
    sg902.attach(PIN_SERVO2);
    sg903.attach(PIN_SERVO3);
    sg903.setPeriodHertz(50);
    sg904.attach(PIN_SERVO4);
    sg905.attach(SERVO_PIN_5);

    sg90.write(0);
    sg902.write(0);
    sg903.write(0);
    sg904.write(0);
    sg905.write(60); // Pince ouverte à l'initialisation
    
    // Définir le mode par défaut
    currentMode = true; // Mode manuel par défaut
}

void loop() {
    // Si en mode automatique, exécuter la séquence
    if (!currentMode) {
        modeAutomatique();
    }
    delay(10); // Petit délai pour éviter de surcharger le processeur
}

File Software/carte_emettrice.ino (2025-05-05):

#include <Wire.h>

#include <WiFi.h>
#include <esp_now.h>

#define MPU6050_ADDR 0x68  // Adresse I²C du MPU-6050
#define FLEX_SENSOR_PIN 39 // GPIO pour le capteur flex
#define BUTTON_PIN 18      // GPIO pour le bouton poussoir
#define FILTER_SAMPLES 30  // Nombre d'échantillons pour le filtrage

uint8_t broadcastAddress[] = {0x30, 0xAE, 0xA4, 0x6F, 0x06, 0x84};

// Variables pour le debounce du bouton
bool buttonPressed = false;
unsigned long lastDebounceTime = 0;
const unsigned long debounceDelay = 50;

// Structure pour envoyer les données des capteurs
struct SensorData {
    float accelX;
    float accelY;
    int flex;
    bool buttonState;
};
SensorData dataToSend;

void OnDataSent(const uint8_t *mac_addr, esp_now_send_status_t status) {
    Serial.println(status == ESP_NOW_SEND_SUCCESS ? "Données envoyées avec succès" : "Échec de l'envoi des données");
}

void setup() {
    Serial.begin(115200);
    Wire.begin(); // Initialisation I²C
    
    // Configuration du bouton (simple INPUT au lieu de INPUT_PULLUP)
    pinMode(BUTTON_PIN, INPUT);
    
    // Vérifier la connexion avec le MPU-6050
    Wire.beginTransmission(MPU6050_ADDR);
    if (Wire.endTransmission() != 0) {
        Serial.println("MPU-6050 non détecté !");
        while (1);
    }
    Serial.println("MPU-6050 détecté !");
    
    // Activer le MPU-6050
    Wire.beginTransmission(MPU6050_ADDR);
    Wire.write(0x6B);
    Wire.write(0x00);
    Wire.endTransmission();
    
    // Initialisation ESP-NOW
    WiFi.mode(WIFI_STA);
    if (esp_now_init() != ESP_OK) {
        Serial.println("Erreur d'initialisation ESP-NOW");
        return;
    }
    esp_now_register_send_cb(OnDataSent);
    
    esp_now_peer_info_t peerInfo;
    memcpy(peerInfo.peer_addr, broadcastAddress, 6);
    peerInfo.channel = 0;
    peerInfo.encrypt = false;
    
    peerInfo.ifidx = WIFI_IF_STA;
    if (esp_now_add_peer(&peerInfo) != ESP_OK) {
        Serial.println("Échec de l'ajout du pair");
        return;
    }
    
    analogReadResolution(12);
}

void readAccelData(int16_t *ax, int16_t *ay) {
    Wire.beginTransmission(MPU6050_ADDR);
    Wire.write(0x3B);
    Wire.endTransmission(false);
    Wire.requestFrom(MPU6050_ADDR, 4, true);
    
    if (Wire.available() == 4) {
        *ax = Wire.read() << 8 | Wire.read();
        *ay = Wire.read() << 8 | Wire.read();
    } else {
        Serial.println("Erreur de lecture MPU-6050 !");
    }
}

void loop() {
    int16_t ax, ay;
    readAccelData(&ax, &ay);
    
    // Lecture de l'état du bouton avec gestion du debounce
    int buttonReading = digitalRead(BUTTON_PIN);
    
    // Si l'état du bouton change, réinitialiser le timer de debounce
    if ((millis() - lastDebounceTime) > debounceDelay) {
        // Mettre à jour l'état du bouton
        dataToSend.buttonState = (buttonReading == HIGH);
        lastDebounceTime = millis();
    }
    
    dataToSend.accelX = ax;
    dataToSend.accelY = ay;
    dataToSend.flex = analogRead(FLEX_SENSOR_PIN);
    
    Serial.println(dataToSend.flex);
    esp_now_send(broadcastAddress, (uint8_t *)&dataToSend, sizeof(dataToSend));
    
    delay(10); 
}

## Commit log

2024-11-28 compte rendu crée
    [carte_robo.kicad_pcb, carte_robo.kicad_sch]
2024-12-09 les deux rop merge
    [carte_robo.kicad_pcb, carte_robo.kicad_sch]
2025-01-07 pcb done
    [Carte_main.kicad_pcb, Carte_main.kicad_sch, carte_robo_pince.kicad_sch]
2025-02-06 last update
    [Carte_main.kicad_pcb, Carte_main.kicad_sch, carte_robo_pince.kicad_pcb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]
2025-05-05 before copy branche matis to main
    [Carte_main-B_Cu.gbr, Carte_main-B_Fab.gbr, Carte_main-B_Mask.gbr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]
